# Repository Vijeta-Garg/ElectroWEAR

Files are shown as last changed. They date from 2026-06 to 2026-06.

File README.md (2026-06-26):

# ElectroWEAR

Inspiration: 
I've been working on an electropneumatically powered mechanotherapy wearable for breast cancer survivors, including in my last iteration (link to that abstract is here: https://www.overleaf.com/read/rxshvgcpytvv#2f1c8a in which I created custom soft actuator structures for this application). However, the last electropneumatic system I made was powered by a 12 Volt battery + hard to integrate into a wearable. I wanted to make an electropneumatic system that can be easier to integrate into a mechanotherapy vest for breast cancer survivors.

What the project does:
The project uses 6 Volts (unlike the earlier iterations which used 12Volts) and smaller components to make the electropneumatic as compact as possible so that it can  be integrated into a garment.

How it works:
A 6V battery powers the circuit while an Arduino Uno relays commands of which component should be on/off according to the code on the Arduino IDE. TIP120 and 1N4007 are there to primarily regulate electrical flow. This circuit powers 2 air pumps/compressors and 2 solenoid valves (although it can be adjusted to power just one of each as was done in this wearable). Furthermore, the circuit is electropneumatic, and it contains a "pneumatic" component in the way the air pumps and solenoid valves are conntected to each other through plastic piping and finally connected to the actuator. This part of the circuit maintains pneumatic flow and allows solenoid valves and air pumps to act as both inlets and outlets (if more than one is used). 

An example of the before and after:

**Before**


**Now: ElectroWEAR**


# Schematic 
This is the wiring diagram/schematic. This includes both the electrical parts of the circuit (contained in the "main circuit board") and the pneumatic parts of the circuit (which are integrated across the wearable rather than in the gray pocket on the bottom-left)!


# Layout 
This is how the circuit is mapped out onto the wearable. Currently the main "control board" is only breadboarded and not PCBed but the files are ready and I just need to order the PCB and substitute it in (that is why that box says breadboard/perfboard/PCB) 
Also note: if one was to wear ElectroWEAR the battery component would theoretically live in their pant pocket or a string bag. 


# PCB (and maybe CAD) 

# How to build this? 
1. Wire up the main electrical component (refer to the schematic in pcb folder). Every solenoid valve or air pump added require the same subset of wiring: TIP120 connected to 1N4007 diode and also connected to the component and GND and Power rails.
2. Connect this circuit to the 6V battery holder. Put the 1.5V batteries inside this battery holder. Remember NOT to plug the 6V directly into the arduino! Plug into power rail to share with components! Either connect by soldering or alligator clips! 
3. Import firmware to arduino IDE and run the circuit
4. Build out the pneumatic section of the circuit by using the schematic as reference. The joint parts are all pneumatic connectors *which look like pipes. Test the circuit out with the pneumatic connections as well. Get pneumatic connectors (plastic tubes) to connect the pipes 
5. Cut out 4 different pockets (preferably of strong material like denim) on a shirt and place the circuit as detailed in the layout diagram. If you have a soft textile actuator (or any output you want the electropneumatic to puff up) place that in the top-left pocket) 
6. Sew the pockets closed and the build is done!
7. Print out the flex PCB design detailed in this repo. Then, unsew the controller pocket and connect that to the arduino + into the pocket instead of the earlier perfboarded/breadboarded version!



# BOM (properly formatted in the bom.csv file in the repo) 
Please note: I don't need reimbursement for any of these materials since I can use research grant money I've gotten for this project! 


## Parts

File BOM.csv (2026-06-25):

SR. No | Items | Quantity | Unit Price | Total price | URL
1 | Solenoid Va | 1 | 9.29 | 9.29 | https://www
2 | 1 battery AA | 1 | 3.35 | 3.35 | https://www
3 | TIP120 Darl | 2 | 0.7 | 1.4 | self-source
4 | Arduino Un | 1 | 14.24 | 14.24 | self-source
5 | 1N4007 dic | 2 | 0.2 | 0.4 | self-source
6 | Air pump (6 | 1 | 4.99 | 4.99 | https://www
7 | 1.5V batteri | 4 | 1.31 | 5.25 | https://www
Total | 8 | 19 |  | 34.52

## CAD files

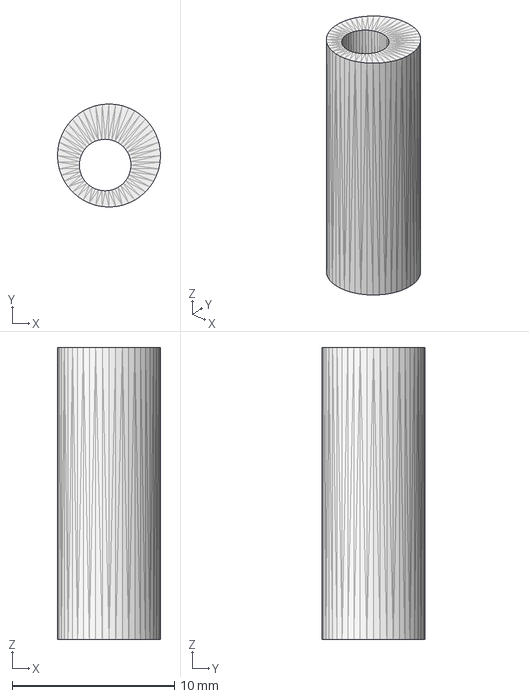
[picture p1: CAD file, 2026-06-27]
CAD/PipeConnector.step
6.35 x 6.35 x 18.0 mm

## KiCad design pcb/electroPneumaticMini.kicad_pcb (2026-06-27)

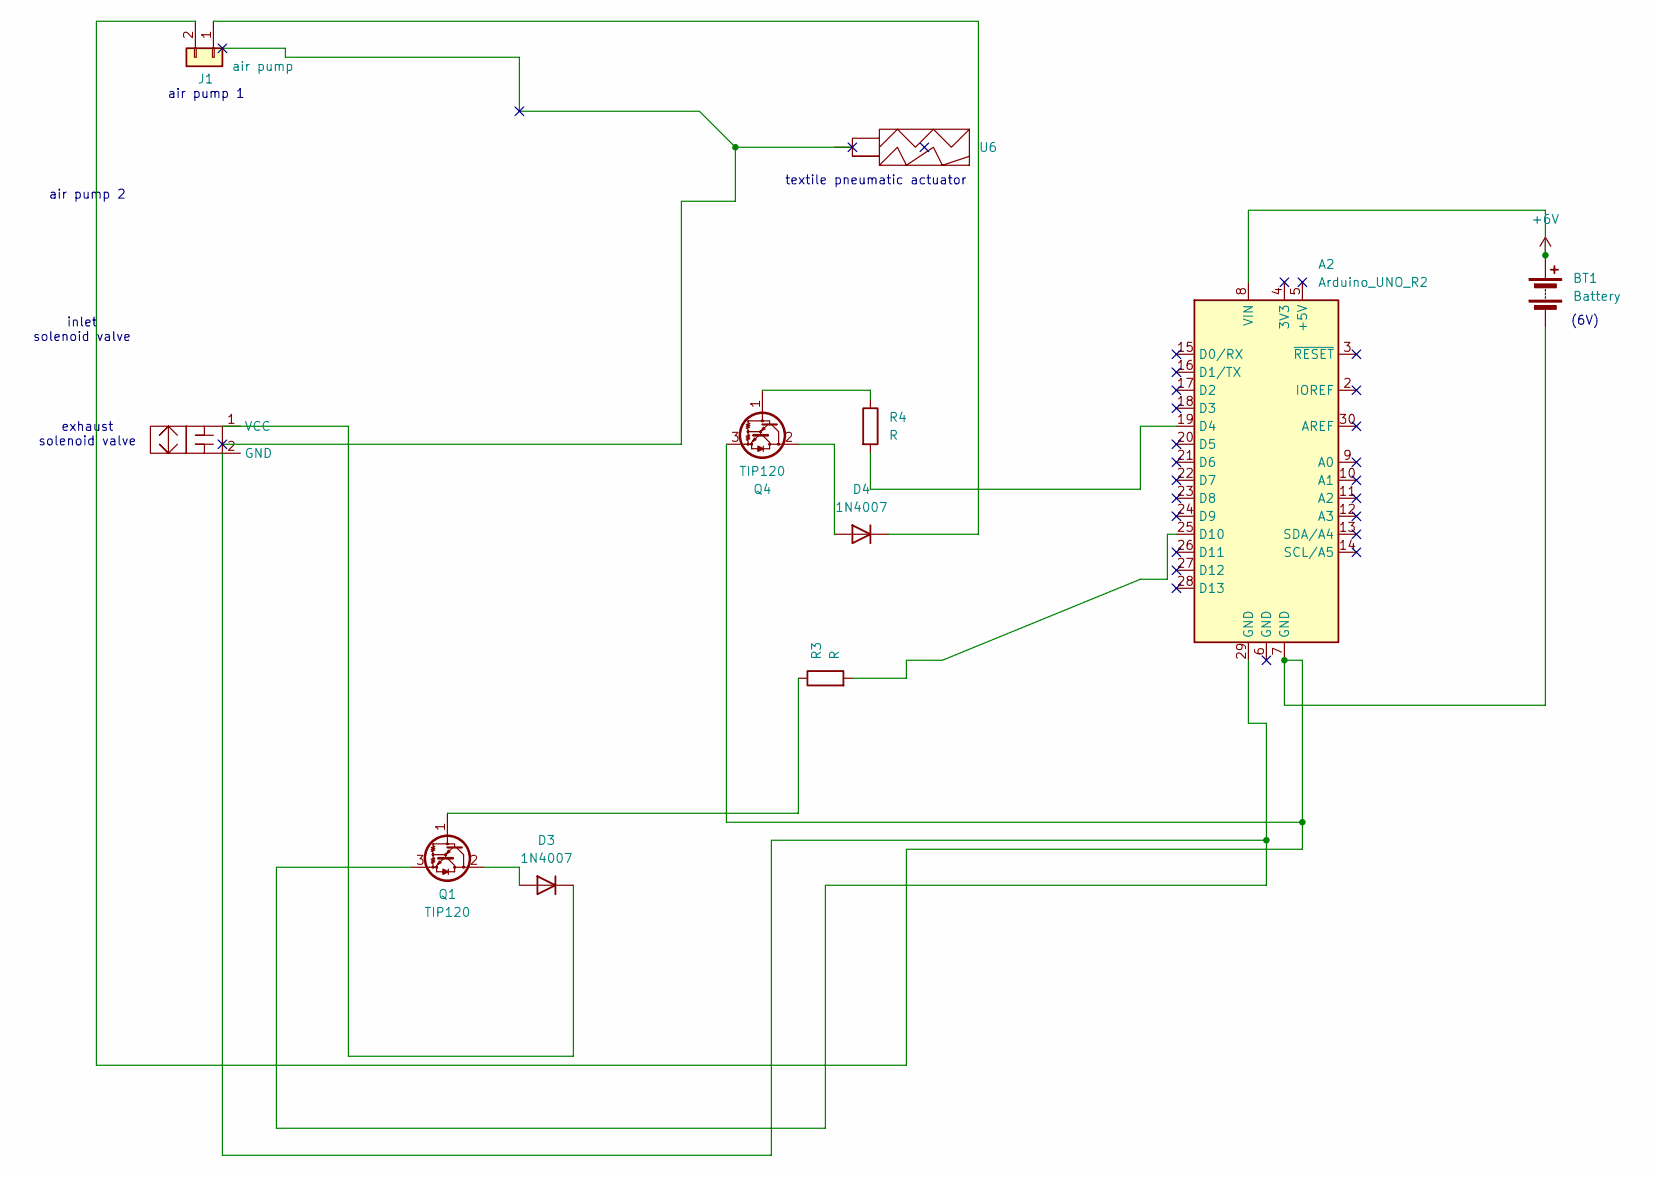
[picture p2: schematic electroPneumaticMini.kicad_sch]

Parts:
A2: Arduino_UNO_R2
BT1: Battery; PinHeader_1x02_P2.54mm_Vertical
D3, D4: 1N4007; D_DO-41_SOD81_P10.16mm_Horizontal
J1: air pump; PinHeader_1x02_P1.00mm_Vertical
Q1, Q4: TIP120; TO-220-3_Vertical
R3, R4: R; R_Axial_DIN0204_L3.6mm_D1.6mm_P7.62mm_Horizontal
U6: (no value)
u5: PinHeader_1x02_P2.54mm_Vertical

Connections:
+6V: A2.8 (VIN), BT1.1 (+)
unnamed: A2.19 (D4), R4.2
unnamed: A2.25 (D10), R3.2
unnamed: A2.7 (GND), BT1.2 (-), J1.2, Q4.3 (E)
unnamed: D3.2 (A), Q1.2 (C)
unnamed: D3.1 (K), u5.1 (VCC)
unnamed: D4.2 (A), Q4.2 (C)
unnamed: D4.1 (K), J1.1
unnamed: Q1.1 (B), R3.1
unnamed: A2.29 (GND), Q1.3 (E), u5.2 (GND)
unnamed: Q4.1 (B), R4.1

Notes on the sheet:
air pump 1
air pump 2
(6V)
inlet solenoid valve
textile pneumatic actuator
exhaust solenoid valve

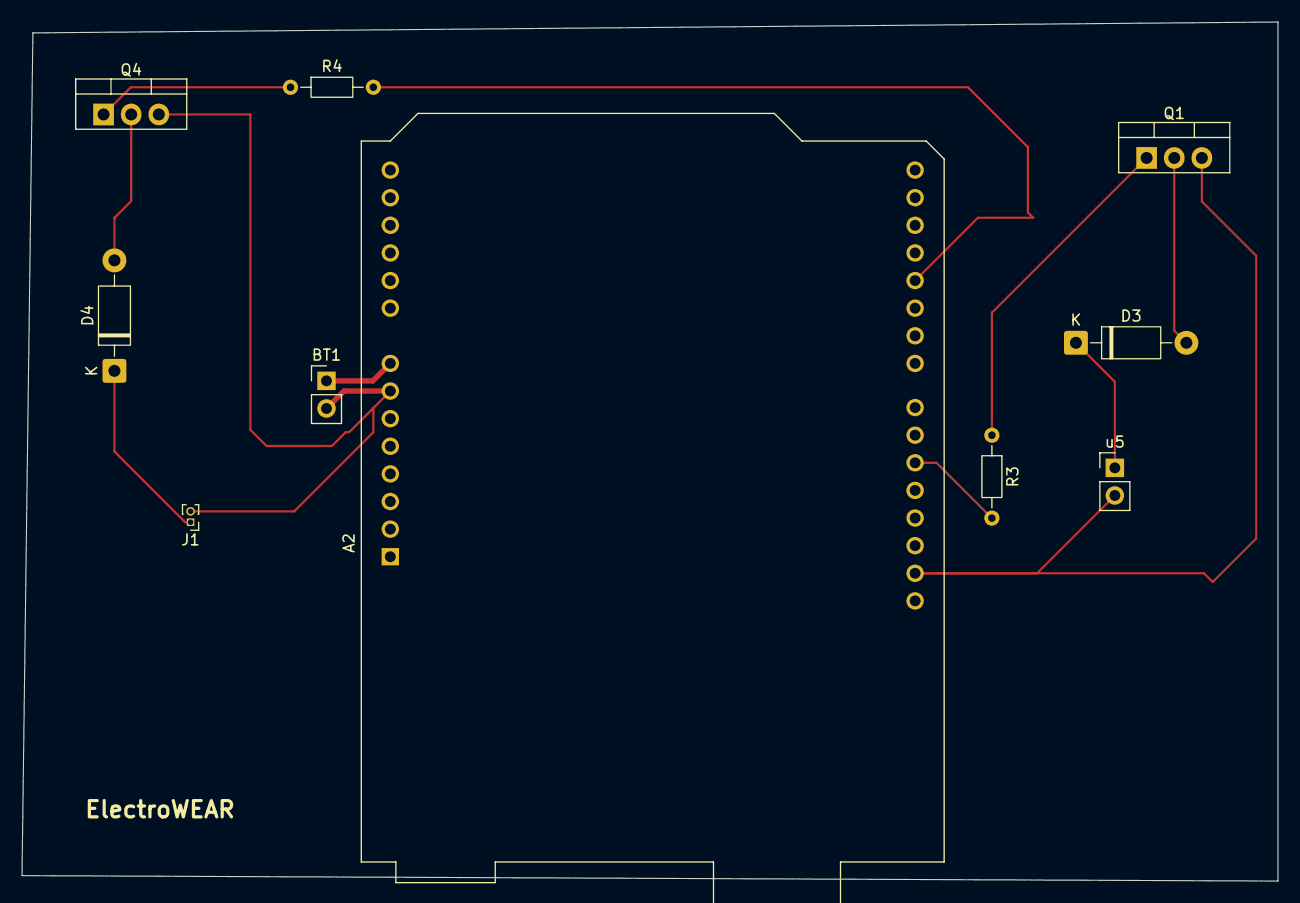
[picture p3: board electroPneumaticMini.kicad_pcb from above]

Board: 2 copper layers, 115.5 x 79.0 mm, 10 parts (0 on the bottom side), 11 nets.

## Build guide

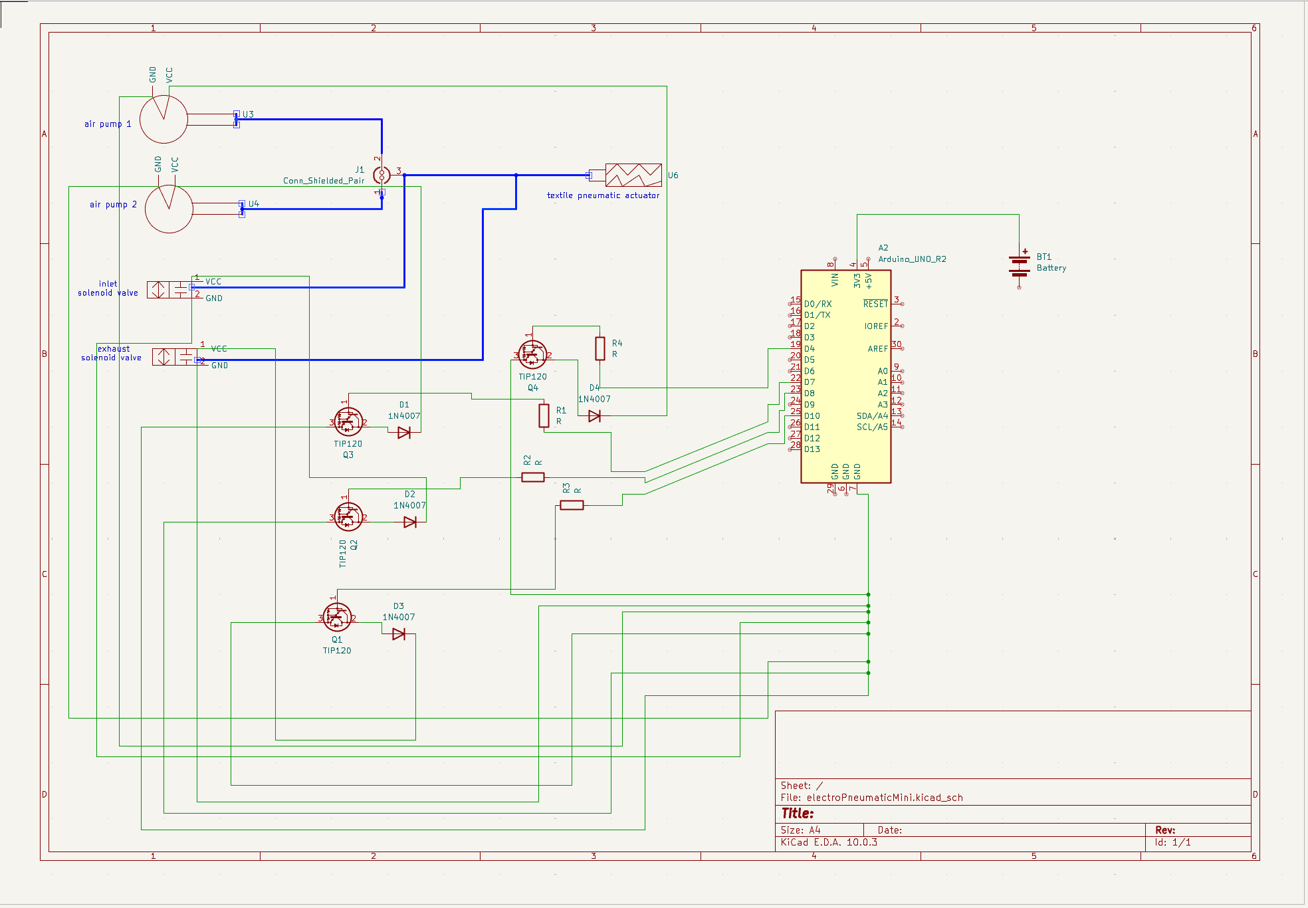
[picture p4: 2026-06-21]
pneumaticwiringDiagram.png

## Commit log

2026-06-25 Update BOM.csv with structured item details
    [BOM.csv]
2026-06-25 Update README with BOM details and funding note
    Added BOM section and clarified funding for materials.
2026-06-25 Update BOM.csv with corrected entries
    Corrected item quantities and prices, and updated URLs.
    [BOM.csv]
2026-06-26 Update README with battery component location details
    Added note about battery component placement for ElectroWEAR.
